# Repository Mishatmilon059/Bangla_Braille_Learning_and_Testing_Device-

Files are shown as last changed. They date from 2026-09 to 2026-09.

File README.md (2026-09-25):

# AI Driven Bangla Braille Learning Device

**Department of Electrical and Electronic Engineering (EEE)**  
**Bangladesh University of Engineering and Technology (BUET)**  
**Course:** EEE 416 — Microprocessor and Embedded Systems Sessional  
**Project Group:** Group 08 (Section A2)  

---

## Project Team Members

| Student Name | Student ID | Academic Affiliation |
|---|:---:|---|
| **Santu Nag** | `2106055` | Department of EEE, Bangladesh University of Engineering and Technology (BUET) |
| **Md. Adib Hasan Audhi** | `2106056` | Department of EEE, Bangladesh University of Engineering and Technology (BUET) |
| **Mishat Hasan Milon** | `2106059` | Department of EEE, Bangladesh University of Engineering and Technology (BUET) |
| **Khalid Mehebub** | `2106065` | Department of EEE, Bangladesh University of Engineering and Technology (BUET) |

---

## Table of Contents

1. [Abstract](#abstract)
2. [System Architecture](#system-architecture)
3. [Hardware Specifications](#hardware-specifications)
4. [Bangla Braille Encoding Standard (50 Characters)](#bangla-braille-encoding-standard-50-characters)
5. [TinyML Pedagogical Model & Empirical Validation](#tinyml-pedagogical-model--empirical-validation)
6. [Repository File & Directory Structure](#repository-file--directory-structure)
7. [Cloning the Repository](#cloning-the-repository)

---

## Abstract

The **Bangla Braille Learning and Testing Device** is an accessible assistive pedagogical system designed for visually impaired learners. Developed as the final capstone design project for **EEE 416 (Microprocessor and Embedded Systems Sessional) at BUET**, the device combines a **6-dot tactile haptic matrix** (coin vibration motors) with **synchronized auditory speech feedback** and an **on-device dual-head neural network** that runs fully offline on an ESP32 microcontroller with zero machine learning runtime overhead. It supports both standalone offline practice and real-time remote classroom assessment via a web-connected teacher portal.

---

## System Architecture

The following diagram illustrates the end-to-end dataflow between specification, training pipelines, the web instrumentation platform, and the physical ESP32 embedded tutor:

```
┌────────────────────────────────────────────────────────────────────────┐
│                        CENTRAL SPECIFICATION                          │
│  spec/engine_spec.json (Features, Thresholds, Normalization Bounds)    │
│  data/braille_map.json (50 Letters, 6-Dot Patterns, Audio Tracks)      │
└───────────────────────────────────┬────────────────────────────────────┘
                                    │
           ┌────────────────────────┼────────────────────────┐
           ▼                        ▼                        ▼
  [tools/gen_engine.py]   [tools/gen_braille_header.py] [tools/gen_audio.py]
           │                        │                        │
  ┌────────┼────────┐               ▼                        ▼
  ▼        ▼        ▼      firmware/braille_map.h       web/audio/ &
web JS   Py Gen   C Header  assets/braille/*.svg         sd_card/mp3/
  │        │        │
  ▼        ▼        │
┌──────┐ ┌──────┐   │
│ Web  │ │ Synth│   │
│ MVP  │ │ Sim  │   │
└──┬───┘ └──┬───┘   │
   │        │       │
   ▼        ▼       │
┌──────────────┐    │
│ 2,242 Rows   │    │
│ (1000 Real + │    │
│  1242 Synth) │    │
└──────┬───────┘    │
       ▼            │
[tools/train.py]    │
       │            │
       ▼            ▼
 ┌──────────────────────────────────────┐
 │       firmware/braille_tutor/        │
 │  model_weights.h (1,734 Floats, 7KB) │
 │  inference.h (0.1ms Forward Pass)    │
 │  rule_engine.h (Fixed Normalization) │
 └──────────────────┬───────────────────┘
                    ▼
 ┌──────────────────────────────────────┐
 │     PHYSICAL EMBEDDED HARDWARE       │
 │ ESP32 · 6 Buttons · 6 Coin Motors    │
 │ ULN2803A · DFPlayer · MicroSD · RTC   │
 └──────────────────────────────────────┘
```

Detailed architectural vector diagrams (SVG and PNG) are located in [`docs/diagrams/`](docs/diagrams/).

---

## Hardware Specifications

### Component List

| Component | Specification | Quantity | Function |
|---|---|:---:|---|
| **Microcontroller** | ESP32-WROOM-32 (38-pin, 240 MHz Dual Core) | 1 | Core compute, TinyML inference, GPIO debounce |
| **Haptic Actuators** | 1027 Coin Vibration Motors (10mm, 3V, 80mA) | 6 | Tactile 6-dot Braille matrix |
| **Motor Driver** | ULN2803A Darlington Transistor Array (DIP-18) | 1 | Inductive load sink & integrated flyback clamping |
| **Input Buttons** | 12×12×7.3mm Tactile Push Buttons | 7 | 6 dot input buttons + 1 submit button |
| **Audio Module** | DFPlayer Mini (FN-M16P MP3 Player) | 1 | Hardware MP3 decoding via UART |
| **Loudspeaker** | 3W 8Ω Enclosed Speaker (40mm) | 1 | Spoken letter pronunciation & audio cues |
| **External Storage** | MicroSD Card SPI Adapter + 16GB MicroSD Card | 1 | Offline storage for 60 spoken audio prompt files |
| **Real-Time Clock** | DS3231 I2C RTC Module | 1 | Session epoch tracking across power cycles |
| **Power Supply** | 5V 2A DC Adapter + 1000 µF 16V Electrolytic Cap | 1 | High-current power rail with inrush decoupling |
| **Resistors & Misc** | 6× 1 kΩ (LED/Pull), 3× 10 kΩ (Strapping pulldowns) | - | Pin protection & pull resistors |
| **Enclosure** | 3D Printed PLA Case & Acrylic Cutout Panel | 1 | Ergonomic desk console housing |

### Canonical Pinout Configuration

The canonical pin assignments (configured in [`firmware/braille_tutor/pins.h`](firmware/braille_tutor/pins.h)) are engineered to avoid ESP32 boot strapping conflicts:

| Peripherals | GPIO Pin | Hardware Configuration & Notes |
|---|:---:|---|
| **Dot Buttons (1–6)** | `GPIO 32, 33, 25, 26, 27, 14` | Internal pull-up enabled (`INPUT_PULLUP`). Active LOW when pressed to GND. |
| **Submit Button** | `GPIO 12` | Boot strapping pin. Pulled to GND during boot; pressed to GND via active switch. |
| **Coin Motors (1–6)** | `GPIO 21, 13, 22, 2, 15, 4` | Connected to ULN2803A Inputs 1–6. Active HIGH drive. ULN2803A COM pin tied to +5V. |
| **DFPlayer Audio** | `GPIO 16 (RX), GPIO 17 (TX)` | ESP32 HardwareSerial (UART2). 1 kΩ series resistor on TX line to suppress noise. |
| **MicroSD Module** | `GPIO 18 (SCK), 19 (MISO), 23 (MOSI), 5 (CS)` | Hardware VSPI interface operating at 20 MHz. |
| **I2C RTC (DS3231)** | `GPIO 21 (SDA), GPIO 22 (SCL)` | Standard I2C bus (optional, activated via `USE_RTC 1` in `pins.h`). |

> [!CAUTION]
> **Electrical Safety & Circuit Protection**:
> **Never drive vibration motors directly from ESP32 GPIOs**: All six coin motors firing simultaneously draw ~480 mA. A ULN2803A Darlington array must be used, with its COM pin tied to +5V for inductive flyback protection.

---

## Bangla Braille Encoding Standard (50 Characters)

The repository implements the official **Bangladesh National Braille Code**, verified against Wikipedia's Bengali Braille standard: [বাংলা ব্রেইল - উইকিপিডিয়া](https://bn.wikipedia.org/wiki/%E0%A6%AC%E0%A6%BE%E0%A6%82%E0%A6%B2%E0%A6%BE_%E0%A6%AC%E0%A7%8D%E0%A6%B0%E0%A7%87%E0%A6%87%E0%A6%B2) and cross-referenced with *World Braille Usage (3rd Edition, Perkins/ICEB)*.

- **11 Vowels**: অ (`1`), আ (`345`), ই (`24`), ঈ (`35`), উ (`136`), ঊ (`1256`), ঋ (`5 + 1235`), এ (`15`), ঐ (`34`), ও (`135`), ঔ (`246`).
- **39 Consonants**: ক (`13`), খ (`1346`), গ (`1245`), ঘ (`126`), ঙ (`346`), চ (`14`), ছ (`16`), জ (`245`), ঝ (`1356`), ঞ (`25`), ট (`23456`), ঠ (`2456`), ড (`1246`), ঢ (`123456`), ণ (`3456`), ত (`2345`), থ (`1456`), দ (`145`), ধ (`2346`), ন (`1345`), প (`1234`), ফ (`124`), ব (`12`), ভ (`1236`), ম (`134`), য (`13456`), র (`1235`), ল (`123`), শ (`146`), ষ (`12346`), স (`234`), হ (`125`), ড় (`12456`), ঢ় (`12356`), য় (`26`), ৎ (`5 + 2345`), ং (`56`), ঃ (`6`), ঁ (`3`).

### Two-Cell Compound Characters (ঋ and ৎ)
In Bengali orthography, ঋ (*ri*) and র (*ra*) share the primary dot matrix `[1, 2, 3, 5]`, while ত (*ta*) and ৎ (*khanda ta*) share `[2, 3, 4, 5]`. To resolve this collision haptically without tactile ambiguity:
- **Two-Cell Representation**: ঋ and ৎ are encoded as two sequential Braille cells.
- **Haptic Timing**: In Learn and Tutor modes, an initial 150 ms pulse on **Dot 5** serves as the indicator prefix, followed by a 200 ms pause, followed by the vibration of the primary letter cell.

---

## TinyML Pedagogical Model & Empirical Validation

### Network Architecture

The on-device pedagogical agent uses a dual-head feedforward neural network:

$$\mathbf{x} \in \mathbb{R}^8 \longrightarrow \text{Dense}(32, \text{ReLU}) \longrightarrow \text{Dense}(16, \text{ReLU}) \longrightarrow \begin{cases} \text{Head}_{\text{TA}} \in \mathbb{R}^3 & (\text{Teaching Action}) \\ \text{Head}_{\text{CS}} \in \mathbb{R}^3 & (\text{Confidence State}) \end{cases}$$

1. **Total Parameters**: 1,734 trainable floating-point weights (6,936 bytes).
2. **Execution Latency**: **~0.1 milliseconds** on an ESP32 at 240 MHz.
3. **Memory Footprint**: 6,936 bytes in Flash (`PROGMEM`) + 192 bytes temporary stack RAM during forward pass. Total memory required: **~7.1 KB of 520 KB SRAM** (< 1.4% capacity).

### Feature Formulation (8 Model Inputs of 14 Logged)

| Feature Name | Type | Range | Description |
|---|:---:|:---:|---|
| `response_time` | float | 0–30,000 ms | Elapsed time from prompt completion to debounced submit press |
| `press_duration` | float | 0–5,000 ms | Average hold duration across raised dot keys |
| `retry_count` | int | 0–10 | Number of re-attempts within the current character trial |
| `prev_accuracy` | float | 0.0–1.0 | Exponential moving average of learner accuracy across past attempts |
| `prev_mastery` | float | 0.0–1.0 | Historical mastery score for the specific character prompt |
| `hint_count` | int | 0–10 | Frequency of tactile/audio hints requested during the trial |
| `current_streak` | int | 0–50 | Number of consecutive correct submissions |
| `wrong_streak` | int | 0–20 | Number of consecutive incorrect submissions |

### Experimental Results (Evaluated on 2,242 Total Trials)

| Task Head | Class Label | Test Support ($N$) | Precision | Recall | F1-Score | Combined Accuracy | Real-Only Accuracy | Majority Baseline |
|---|---|:---:|:---:|:---:|:---:|:---:|:---:|:---:|
| **Teaching Action** | `REPEAT` | 90 | 1.000 | 0.989 | **0.994** | **99.41%** | **98.56%** | 46.59% |
| | `HINT` | 90 | 0.978 | 1.000 | **0.989** | | | |
| | `NORMAL_PRACTICE` | 157 | 1.000 | 0.994 | **0.997** | | | |
| **Confidence State** | `CONFIDENT` | 94 | 0.910 | 0.968 | **0.938** | **94.07%** | **91.37%** | 42.43% |
| | `HESITANT` | 143 | 0.956 | 0.902 | **0.928** | | | |
| | `GUESSING` | 100 | 0.951 | 0.970 | **0.960** | | | |

---

## Repository File & Directory Structure

```
.
├── assets/
│   └── braille/                     # Generated vector SVGs and PNG contact sheets for all 50 characters
├── Bangla_Braille_39_Consonants_PNG/# 39 Consonant reference cards citing World Braille Usage (3rd Ed.)
├── braille_img/                     # Ground-truth reference images for Bengali vowels
├── data/
│   ├── braille_map.json             # Primary ground truth: 50 letters, dot arrays, audio mappings
│   ├── braille_verified/            # Cropped verification cell images
│   └── braille_verified.zip         # Packaged visual verification archives
├── dataset/
│   ├── real.csv                     # Raw human participant trial logs (P01-P04)
│   ├── real_v2.csv, real_v3.csv     # Preprocessed and validated human attempt datasets (1,000 trials)
│   ├── synthetic.csv                # Calibrated synthetic learner simulations
│   ├── synthetic_2k.csv             # 1,242 synthetic rows matched to empirical distributions
│   └── synthetic_targeted.csv       # Targeted rare-class training samples
├── docs/
│   ├── diagrams/                    # System diagrams (PNG & SVG)
│   ├── presentation/                # Academic presentation slide decks and progress reports
│   │   ├── BraillePresentation.pptx # Technical presentation slides
│   │   ├── EEE416_G8_FinalDemo.pptx # Final demonstration deck
│   │   └── G8 Project Progress.pdf  # Project milestone documentation
│   ├── FINAL_DEMO_CHECKLIST.md      # Hardware demonstration and QA checklist
│   └── PROJECT_REPORT.md            # Comprehensive scientific technical report
├── enclosure/
│   ├── 3d_preview.html              # Interactive Three.js 3D web preview of the enclosure
│   ├── braille_tutor_case.scad      # OpenSCAD 3D parametric desk console case
│   ├── top_panel.stl                # Ready-to-print 3D mesh for top button/motor panel
│   ├── top_panel_cutout.svg         # 1:1 scale 2D vector file for laser-cut acrylic top plates
│   └── top_panel_layout.scad        # Parametric layout generator for component cutouts
├── firmware/
│   ├── braille_tutor/               # Main autonomous offline embedded firmware
│   │   ├── braille_map.h            # [Generated] 50-letter dot lookup tables & prefix flags
│   │   ├── braille_tutor.ino        # Core microcontroller application loop
│   │   ├── hardware.h               # Peripheral abstractions (audio, motors, debounce)
│   │   ├── inference.h              # Pure C forward pass for 1,734-param neural network
│   │   ├── learner_state.h          # On-device feature tracker and moving average calculator
│   │   ├── model_weights.h          # [Generated] Static C float arrays of trained MLP weights
│   │   ├── pins.h                   # Canonical GPIO pin mappings and hardware macros
│   │   ├── platformio.ini           # PlatformIO project configuration
│   │   └── rule_engine.h            # [Generated] Feature normalizer & rule fallback logic
│   ├── t11_ml_test/                 # Side-by-side firmware comparing TinyML decisions vs rule engine
│   ├── t12_ml_complete/             # t11_ml_test + per-student personalization (real student_id, saved mastery per student)
│   └── tests/                       # Staged bring-up sketches (t1_blink to t11_testing)
├── models/
│   ├── golden_vectors.json          # 20 boot self-test vectors with expected model outputs
│   ├── metrics_final.json           # Comprehensive evaluation metrics, confusion matrices & F1 scores
│   └── model.tflite                 # 8-bit quantized reference model
├── sd_card/
│   └── mp3/                         # 60 zero-padded MP3 audio files (0001.mp3 to 0060.mp3) for DFPlayer
├── spec/
│   └── engine_spec.json             # Central specification for features, thresholds, and outputs
├── supabase/
│   ├── full_setup.sql               # Complete idempotent database schema (commands, attempts, telemetry)
│   └── schema.sql                   # Base attempts table schema
├── tools/                           # Python pipelines for code generation, training & validation
│   ├── gen_audio.py                 # Generates spoken audio prompts via TTS
│   ├── gen_braille_header.py        # Generates firmware/braille_tutor/braille_map.h
│   ├── gen_braille_images.py        # Generates vector and PNG character visual representations
│   ├── gen_engine.py                # Transpiles engine_spec.json into JS, C, and Python rule engines
│   ├── run_all_tests.py             # Master automated validation suite
│   ├── test_parity.py               # Cross-runtime parity verification (JS == C == Python)
│   ├── train_and_export.py          # Trains dual-head MLP and exports model_weights.h
│   └── validate_braille_map.py      # Verifies 50 characters against national standard
├── web/                             # Browser data-collection application & teacher telemetry portal
│   ├── audio/                       # Web-optimized audio assets
│   ├── data/braille_map.json        # Frontend character configuration
│   ├── app.js                       # Core interactive student tutor web client
│   ├── config.js                    # Supabase public client connection configuration
│   ├── index.html                   # Student practice & data collection interface
│   ├── teacher.html, teacher.js     # Real-time remote teacher control & assessment dashboard
│   ├── remote_control.html          # Lightweight single-character trigger panel
│   └── rule_engine.js               # [Generated] In-browser pedagogical classification engine
├── package.json                     # Project manifest and dev server scripts
├── requirements.txt                 # Python dependencies
└── USER_MANUAL.md                   # Bengali user guide for participant testing
```

---

## Cloning the Repository

To clone this repository and inspect the project files:

```bash
git clone https://github.com/Mishatmilon059/Bangla_Braille_Learning_and_Testing_Device-.git
cd Bangla_Braille_Learning_and_Testing_Device-
```

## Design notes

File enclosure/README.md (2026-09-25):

# Bangla Braille Tutor — enclosure & fabrication

Mechanical files for the ESP32 Bangla Braille Tutor console. The top face is
the part that matters: it carries every component the learner touches.

## Three parts, one enclosure

The enclosure is three separate printed parts, stacked and screwed together:

1. **`top_panel.stl`** — the flat top panel. Already printed.
2. **`case_walls.stl`** — an open-top, open-bottom frame the panel rests
   on. **Print this next.**
3. **`case_base.stl`** — a flat cover that closes the bottom. **Print this
   too.**

`case_walls.stl` and `case_base.stl` are generated straight from
`tools/gen_case_parts_3d.py`, the same no-OpenSCAD-needed approach as
`top_panel.stl` -- `case_walls.scad` / `case_base.scad` are the OpenSCAD
source of truth for the same two parts, for anyone who does have OpenSCAD.

Stack order, bottom to top: the base cover, then the wall frame, then the
top panel on top. Four M3 screws drop down
through the panel's four corner holes, through the frame's open interior,
into the screw bosses moulded into the base cover.

Heights: 2.8 mm (panel) + 45.2 mm (walls) + 2.8 mm (base) = 50.8 mm (2 in)
total, ground to top panel. All three share the same 210 × 140 mm footprint
and 8 mm corner radius (from `top_panel_layout.scad`), so nothing needs
separate measuring — they line up by construction.

## Files

### The top panel, which is the part that gets made

| File | Purpose | Opens in |
|---|---|---|
| `top_panel.stl` | **The 3D top panel.** Watertight solid, mm, print or view it. **Generated.** | Cura, PrusaSlicer, Bambu Studio, any mesh viewer |
| `top_panel_3d.html` | **3D viewer for the top panel.** Orbit, preset views. **Generated.** | any browser (needs internet for the CDN) |
| `top_panel_cutout.svg` | 1:1 cut file for the same panel. **Generated.** | Laser cutter, Illustrator, CorelDRAW, Inkscape |
| `top_panel_layout.scad` | The same coordinates as OpenSCAD constants. **Generated.** | included by the case file |

### The rest

| File | Purpose |
|---|---|
| `case_walls.stl` | **The middle part.** Watertight solid, mm, ready for a slicer. An open-top/open-bottom frame, 45.2 mm tall, same footprint and corner radius as the top panel. No panel cutouts (motor/button/speaker) — those are already on the printed panel. Carries the wire pass-through hole, offset to one side of the back wall. **Generated.** |
| `case_base.stl` | **The base half.** Watertight solid, mm, ready for a slicer. Closes underneath: a 2.8 mm flat cover, same footprint and corner radius as the top panel, with M3 screw bosses under the panel's clearance holes. **Generated.** |
| `case_walls.scad` | OpenSCAD source of truth for `case_walls.stl`, for anyone who has OpenSCAD instead of Python |
| `case_base.scad` | OpenSCAD source of truth for `case_base.stl` |
| `braille_tutor_case.scad` | Superseded. An all-in-one alternative that merges the top panel and the walls into a single printed part — duplicates `top_panel.stl` rather than pairing with it. Use `case_walls.stl`/`.scad` instead unless you want a single-part top half printed from scratch |
| `3d_preview.html` | Superseded. An older mockup of the whole console with a layout that no longer matches anything. Nothing is made from it. |
| `case_full_3d.html` | 3D viewer: base cover only, side walls only, or the complete assembly (with the already-printed top panel shown for reference). **Generated by hand, not a script** -- built to the same numbers as the two `.scad` files |

Every generated file traces to one place. Re-run these after any change; never
hand-edit the outputs.

```
python tools/gen_top_panel.py       # SVG + SCAD layout, validates clearances
python tools/gen_top_panel_3d.py    # top_panel.stl + its HTML viewer
python tools/gen_case_parts_3d.py   # case_walls.stl + case_base.stl
```

[`tools/gen_top_panel.py`](../tools/gen_top_panel.py) holds the numbers.
[`tools/gen_top_panel_3d.py`](../tools/gen_top_panel_3d.py) and
[`tools/gen_case_parts_3d.py`](../tools/gen_case_parts_3d.py) import them, so
none of the three printed parts can drift out of alignment with each other.

### The STL

A flat plate, 210 x 140 x 2.8 mm, with all 54 holes. No walls, no skirt, no
base. It is built without a mesh library, so it is verified rather than
trusted:

| Check | Result |
|---|---|
| Triangles | 12,184 |
| Non-manifold edges | 0, watertight |
| Volume vs analytic | agrees to 1.7e-15 relative |
| Bounding box | 210.000 x 140.000 x 2.800 mm |
| Degenerate triangles | 0 |

Printed in PLA at 100% that is about 96 g of material. Print it flat on the
bed, holes vertical, no supports needed.

### The viewer renders the same mesh

`top_panel_3d.html` embeds the verified triangulation rather than rebuilding
the shape in the browser. `THREE.ExtrudeGeometry` is deliberately not used:
its hole bridging emits degenerate slivers, and `EdgesGeometry` then infers
edges along them, which drew a phantom line joining two neighbouring button
holes. The panel itself was solid there the whole time. Outlines are now drawn
straight from the ring loops, so nothing is inferred and the viewer cannot
disagree with the STL.

### Spacing between holes

Both grids share a 30 mm pitch, horizontally and vertically.

| Between | Pitch | Hole | Gap of material |
|---|---|---|---|
| Button to button, left-right | 30 mm | 12.4 mm | 17.6 mm |
| Button to button, top-down | 30 mm | 12.4 mm | 17.6 mm |
| Motor to motor, left-right | 30 mm | 10.4 mm | 19.6 mm |
| Motor to motor, top-down | 30 mm | 10.4 mm | 19.6 mm |

The submit button keeps the same 30 mm pitch below the last button row, so it
also has 17.6 mm of material above it.

The generator refuses to pass if any two cuts come within 2 mm of each other
or of the panel rim. Current worst cases: 6.40 mm of material from a corner
screw to the rim, and a 2.50 mm web between two adjacent grill holes.

## Parts the top face is cut for

| Component | Qty | Part size | Cutout |
|---|---|---|---|
| Tactile push button, 4-pin | 7 | 12.0 × 12.0 mm body, 6.0 mm tall | 12.4 mm square, 0.5 mm corner relief |
| Coin vibration motor | 6 | Ø 10.0 mm, 3.0 mm thick | Ø 10.4 mm |
| Speaker | 1 | Ø 40.0 mm | 37 × Ø 2.5 mm over a Ø 34.5 mm area |
| M3 machine screw | 4 | M3 | Ø 3.2 mm |

Button caps are white for dots 1–3, red for dots 4–6, and yellow for submit.

**Fit.** Every cutout is 0.4 mm larger than its part, 0.2 mm per side. Cut on
the path centreline and let the kerf give the running clearance; on a laser
that typically lands within a tenth of a millimetre.

Button bodies press **up** through their square holes, so the 2.8 mm panel
captures each switch just under its cap and 3.2 mm of body stands proud.
Motors bond into their round holes with the face **flush** to the panel top,
so the fingertip rests on the motor itself rather than on plastic over it.
Motor leads pass back down through the same hole.

## Layout

210 × 140 mm, 8 mm corner radius, 2.8 mm sheet.

Two 3 × 2 blocks share one 30 mm grid, with rows at y = 26, 56 and 86 mm.
Dots 1-2-3 run down the left column of each block and 4-5-6 down the right,
so dot N sits on the same line whether the learner is feeling it or pressing
it. The motor block centres on x = 52, the button block on x = 158, and the
submit button sits between the two button columns at x = 158, y = 116,
carrying the same 30 mm pitch down from the last row.

The speaker grill centres on x = 105, the exact panel centre line, at
y = 112. Its perforated area stops at Ø 34.5 mm so the Ø 40 mm speaker frame
seats against solid material.

Corner screws sit 8 mm in from both edges, on the corner-radius centres.

## The side walls

`case_walls.scad` is an open-top, open-bottom rounded-rectangle tube that the
already-printed top panel rests on. It shares `PANEL_W`, `PANEL_H` and
`CORNER_R` from `top_panel_layout.scad`, so its footprint and corner radius
match the panel exactly -- the panel sits flush on its top rim, no fitting.

Height: the brief is a total assembled height of 2 in (50.8 mm), ground to
top panel. The panel itself is 2.8 mm and the base cover (below) is another
2.8 mm, so the walls carry the rest: 50.8 - 2.8 - 2.8 = 45.2 mm.

It has none of the panel's own cutouts (motor, button, speaker) -- those are
already on the printed panel. The four M3 screws that pass down through the
panel's corner holes land inboard of the wall thickness, in the frame's open
interior, so the walls don't need their own screw holes either.

| Property | Value |
|---|---|
| Footprint | 210 × 140 mm, 8 mm corner radius (same as the top panel) |
| Height | 45.2 mm |
| Wall thickness | 2.8 mm, matching the top panel |
| Wire pass-through | Ø 8 mm round hole through the back wall, offset to one side (x = 40, not the wall's centre at x = 105) at z = 20 mm, for the power/USB cable |

- **Material:** PLA, PETG or ABS
- **Layer height:** 0.20 mm, or 0.16 mm for a smoother finish
- **Infill:** 20–30% gyroid or grid
- **Supports:** none needed; open top and bottom, no overhangs

`case_walls.stl` is built as 8 independent solids (4 corners, 4 straight
strips, one of them with the wire hole actually cut through it) concatenated
into one file -- they only ever touch a neighbour at a shared, zero-area
face, never overlap, so each is checked on its own:

| Check (each of the 8 pieces) | Result |
|---|---|
| Non-manifold edges | 0, watertight |
| Volume vs analytic | within 0.1%, the polygon-vs-circle/arc discretisation |
| Degenerate triangles | 0 |
| Total | 996 triangles, 85,596.6 mm3 |

## The base cover

`case_base.scad` closes underneath the walls. Same footprint and corner
radius as the top panel and the walls, so all three line up without fitting.

| Property | Value |
|---|---|
| Footprint | 210 × 140 mm, 8 mm corner radius (same as the top panel) |
| Thickness | 2.8 mm (flat cover) |
| Assembled height | 2.8 mm panel + 45.2 mm walls + 2.8 mm cover = 50.8 mm (2 in) total |
| Screw bosses | 4, Ø 7 mm OD × 10 mm tall, Ø 2.6 mm self-tapping pilot for M3, centred on the same `SCREW_POS` as the top panel's clearance holes; they rise into the walls' clear interior |

Flat and thin, it prints supportless, flat side down, same as the top panel.

- **Material / layer height / infill:** same as the walls, above.
- **Fasteners:** the same 4 × M3 screws that pass through the top panel and
  down through the walls thread into these bosses from underneath.

`case_base.stl` is the plate plus the 4 bosses, 5 independent solids
(touching, not overlapping) concatenated the same way as the walls:

| Check (each of the 5 pieces) | Result |
|---|---|
| Non-manifold edges | 0, watertight |
| Volume vs analytic | within 0.3% (the bosses' small radius makes their circle-discretisation error the largest of any part here) |
| Degenerate triangles | 0 |
| Total | 1,932 triangles, 83,489.0 mm3 |

## Known gap

`3d_preview.html` hardcodes its own copy of the geometry and still shows the
older layout: round button holes, a different grid, and a smaller grill. It is
a presentation mockup, not a fabrication source, so nothing is cut or printed
from it. Regenerate or retire it before using it to check dimensions.

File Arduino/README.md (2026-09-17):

# Arduino sketchbook — bench prototypes

This folder is the Arduino IDE sketchbook used while the hardware was being
built on a breadboard. Point the IDE at this directory (File > Preferences >
Sketchbook location) and the bundled `libraries/DFRobotDFPlayerMini` is picked
up automatically, so nothing needs installing.

These are **not** the shipping firmware. The deliverable is
[`firmware/braille_tutor/`](../firmware/braille_tutor/), with its staged
bring-up sketches in [`firmware/tests/`](../firmware/tests/). What lives here is
the earlier, single-file lineage that proved each peripheral by hand.

## Read this before flashing anything

The pin assignments here are the ones that were physically wired on the
breadboard. They are **different from** the canonical map in
[`firmware/braille_tutor/pins.h`](../firmware/braille_tutor/pins.h), which moved
the buttons and motors onto pins chosen for their pull-ups and strapping
behaviour. Do not mix a sketch from this folder with wiring built to `pins.h`.

| | this sketchbook | `pins.h` |
|---|---|---|
| dot buttons | 4, 5, 15, 19, 21, 22 | 32, 33, 25, 26, 27, 14 |
| motors | 13, 14, 26, 27, 32, 33 | 13, 4, 21, 22, 2, 15 |
| DFPlayer RX / TX | 25 / 23 | 16 / 17 |
| submit / enter | 18 / 23, 34 or 16 | 34 (submit) |

## The sketches, in the order they were built

| # | Sketch | Adds | Input |
|---|---|---|---|
| 1 | `p1_pin_tester` | nothing — raw pin diagnostic, no debounce | buttons |
| 2 | `p2_motor_letters` | six vibration motors | serial, 1-37 |
| 3 | `p3_audio_and_vibrate` | DFPlayer audio on top of the motors | serial, 1-50 |
| 4 | `p4_chord_typing` | 6-dot chord input, submit, enter | buttons |
| 5 | `p5_chord_audio_vibrate` | buttons + audio + vibration together | buttons |
| 6 | `p6_dual_mode` | typing mode (audio only) and tutor mode (audio + vibration) | buttons and serial |

## The one that works: `milse1`

`milse1` is the build confirmed working on the bench: speaker, all seven
buttons and all six motors. Flash this one to demo the breadboard. The `p*`
sketches above are the history that led to it.

It is `p6_dual_mode` with five differences:

| | `p6_dual_mode` | `milse1` |
|---|---|---|
| Enter button | GPIO 16, `INPUT_PULLUP` | GPIO 34, plain `INPUT` |
| DFPlayer pin macros | `PIN_DF_RX` / `PIN_DF_TX` | `PIN_DF_ESP_RX` / `PIN_DF_ESP_TX` |
| Track addressing | `playMp3Folder()` | `play()` |
| Volume | 22 | 25 |
| Settle before `begin()` | 500 ms | 1000 ms |

Three notes on it, none a reason to change working hardware:

- **`play()` rather than `playMp3Folder()`.** `play(n)` takes the nth file in
  the card's index order rather than resolving `/mp3/000n.mp3` by name. It is
  correct here because the card was written once, in order, with nothing else
  on it. Rewrite or reorder the card and the mapping can shift.
- **Enter on GPIO 34 with plain `INPUT`.** More honest than the
  `INPUT_PULLUP` it replaced, since GPIO 34 has no internal pull-up to
  enable. The pin still floats without an external 10k to 3V3, so Enter can
  self-trigger. Add the resistor if you see phantom message prints.
- **The `begin()` failure branch is unreachable.** With `isACK` false the
  library returns `... || !isACK`, so those four "Check:" hints never print.
  Harmless while the audio works; misleading the next time it does not.

## `final_working_20260907_1017`

Saved 7 September 2026, 10:17. Same hardware and pins as `milse1`, but a
different program and a different Braille table.

The program is a three-mode menu driven over serial: `L` enters Learn, which
speaks a letter and vibrates its dots; `T` enters Test, which speaks a letter
and scores the dots you press; `M` or the Enter button returns to the menu and
prints the running score. It has no typing-to-text mode, so nothing does a
reverse pattern lookup.

**Its `BRAILLE_PATTERN` table is not usable as ground truth.** Every hex value
does agree with its own dot-list comment, so there are no transcription typos,
but the table itself is not one-to-one:

- **34 distinct patterns for 50 letters.** Twelve patterns are shared by 28
  letters. Dots 1-4-5 is listed as the answer for ঈ, ঙ and দ at once; dots
  1-2-4-5 for ঋ, গ and ং; dots 1-2-4-5-6 for ও, ঢ and ড়. Six dots give 63
  distinct non-empty patterns, so 50 letters fit with room to spare. Collisions
  mean the chart was misread, not that the encoding ran out of room.
- **It contradicts `firmware/braille_tutor/braille_map.h` on 33 of 50
  letters**, including 10 of the 11 that map marks as verified against a
  supplied chart image. For আ the verified pattern is dots 3-4-5 and this table
  says dots 1-2.

Test mode still scores each question, because it compares against the pattern
at a known index rather than searching. But a collided letter teaches the
learner two contradictory answers, and rows logged from it would corrupt the
training set. `tools/validate_braille_map.py` exists for exactly this check and
says so in its own docstring. Reconcile the chart against the images in
`braille_img/` before treating this table as correct.

## Known problems, kept unfixed on purpose

Each sketch reproduces what was actually on the bench, so the flaws are
documented rather than patched. The fixes all live in the `firmware/` tree.

- **GPIO 34 has no internal pull-up.** `p5` calls
  `pinMode(enterButtonPin, INPUT_PULLUP)` on GPIO 34, which is input-only. The
  call is a no-op and the button floats. It needs an external 10k to 3V3.
  `p6` has since moved Enter to GPIO 16, which does have one. Note that
  GPIO 16/17 are wired to PSRAM on ESP32-WROVER modules and unusable there;
  `p6` assumes a WROOM.
- **GPIO 23 is triple-booked.** It is "Submit" in `p1`, "Enter" in `p4`, and the
  DFPlayer TX line in `p5`/`p6`.
- **`p2` carries a stale dictionary.** Its 37-letter table disagrees with the
  canonical 50-letter table on three characters: খ (`0x2D` vs `0x28`), ঝ (`0x35`
  vs `0x34`) and ভ (`0x27` vs `0x18`). The 50-letter table in `p3`/`p5`/`p6`
  matches `firmware/braille_tutor/braille_map.h` and is the one to trust.
- **`p3` sets an out-of-range volume.** `dfPlayer.volume(50)`; the part accepts
  0-30. `p5` uses 30 and `p6` uses 22.
- **`p3` and `p5` address audio with `play()`, `p6` with `playMp3Folder()`.**
  `play(n)` takes the nth file in the card's index order, which depends on the
  order the files were written. `playMp3Folder(n)` resolves `/mp3/000n.mp3` by
  name and is the reliable one, but it needs `mp3/` at the card root. Copy the
  contents of `sd_card/`, not the `sd_card` folder itself.
- **Keep `begin()`'s isACK argument true.** The library returns
  `... || !isACK`, so passing false makes `begin()` report success with no
  module attached, and disables the acknowledgement that would surface any
  later command failure. A dead DFPlayer then looks exactly like a working
  one.
- **ঋ and র share pattern `0x17`.** The decoders skip index 6 during the
  one-cell search, so a bare `0x17` chord resolves to র and ঋ is reachable only
  through the dot-5 two-cell prefix.

## `_archive/`

`chord_typing_dot6_prefix` is an earlier `p4` that used a **dot-6** prefix for ৎ
and a dot-5 prefix for ঋ. That was dropped in favour of a single dot-5 prefix
for both, which is what `p4`, `p5` and `p6` implement. Kept only for the
history; the IDE will still open it.

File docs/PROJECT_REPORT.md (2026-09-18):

# AI-Assisted Bangla Braille Tutor — End-to-End Project Report

**Repository:** `Mishatmilon059/Bangla_Braille_Learning_and_Testing_Device-`
**Branch:** `main`
**Report date:** 30 July 2026
**Status:** software complete and tested · data collection not started · hardware not built

---

## 1. What this project is

A system that teaches Bangla Braille, records how learners perform, trains a
small neural network on those recordings, and runs that network **entirely
offline on an ESP32 microcontroller** driving six vibration motors, six push
buttons, and spoken audio.

It has three parts:

| Part | Purpose | Status |
|---|---|---|
| **Web MVP** | Data-collection instrument. Teaches, and records every attempt. | ✅ Built and tested |
| **Training pipeline** | CSV → multi-task network → 8-bit model → C header | ✅ Built and tested |
| **ESP32 firmware** | Runs the model on hardware, no internet | ✅ Written, ⚠ not run on real hardware |

---

## 2. Honest summary — read this first

Three statements that must appear in any write-up of this project:

**2.1 The model imitates a rule engine; it does not discover teaching policy.**
The training labels are produced by a hand-written rule engine. A network
trained on them learns to reproduce that rule engine — measured at 100%
agreement on this synthetic-only run. This is a legitimate TinyML result
(train → quantize → deploy → real-time offline inference in 5,480 bytes), but
describing it as autonomous adaptive learning would be false. One question —
*"where did the labels come from?"* — exposes the difference.

**2.2 No real learner data exists yet.** Every accuracy figure in this report
comes from a synthetic-data pipeline test. Those numbers are circular: the rows
were simulated and labelled by the same rule engine the network is asked to
reproduce. They prove the *pipeline* works. They say nothing about real people.

**2.3 39 of 50 Braille characters are unverified.** The 11 vowels were read
from supplied reference images. The 39 consonants still carry placeholder
patterns derived from the Bharati Braille standard. Evidence they are not
reliable: of 11 vowel guesses, **1 was wrong**. At that rate roughly 3–4
consonants are also wrong, and there is no way to tell which without images.

---

## 3. Architecture

```
                        ┌──────────────────────────┐
                        │  spec/engine_spec.json   │  ← source of truth
                        │  data/braille_map.json   │
                        └────────────┬─────────────┘
                                     │  code generators
              ┌──────────────────────┼──────────────────────┐
              ▼                      ▼                      ▼
      web/rule_engine.js    tools/rule_engine_gen.py   firmware/rule_engine.h
              │                      │                      │
              ▼                      ▼                      ▼
      ┌───────────────┐      ┌──────────────┐      ┌────────────────┐
      │  Web MVP      │      │  Synthetic   │      │  ESP32         │
      │  (browser)    │      │  generator   │      │  firmware      │
      └───────┬───────┘      └──────┬───────┘      └────────┬───────┘
              │ real rows           │ synthetic rows        │
              └──────────┬──────────┘                       │
                         ▼                                  │
                  ┌─────────────┐                           │
                  │  Supabase   │                           │
                  │  attempts   │                           │
                  └──────┬──────┘                           │
                         ▼                                  │
                  ┌─────────────┐                           │
                  │  train.py   │  790 params               │
                  └──────┬──────┘                           │
                         ▼                                  │
                  model.tflite (5,480 B int8) ──────────────┘
```

### 3.1 The central design decision

Everything downstream is **generated from two data files**. This exists to
eliminate one specific failure: the browser and the ESP32 computing features or
rules slightly differently, so a model trained on browser data misbehaves on
hardware. That class of bug is invisible until integration and expensive to
find then.

The rule engine is written **once** in `spec/engine_spec.json` and generated
into JavaScript, C, and Python. `tools/test_parity.py` pushes **3,000 feature
vectors** — including values sitting exactly on every decision threshold —
through all three and asserts identical output for the teaching action, the
confidence state, and all 14 normalized values. It passes.

Feature normalization uses **fixed ranges from the spec, not statistics derived
from the dataset**. A dataset-derived scale would shift every time the model is
retrained, silently desynchronising the ESP32 from the model it is running.

---

## 4. The learning model

### 4.1 Features — 14 logged, 4 fed to the model

All 14 are sampled at three distinct moments (web and firmware must sample
identically or the model misbehaves on hardware) and kept in the database/CSV
schema for logging and analysis. Only the 4 marked **model input** below are
actually fed to the neural network — the other 10 are read by no rule in
`spec/engine_spec.json`, so the model has nothing to gain from seeing them.
`hint_count` in particular is now an exact function of `retry_count`
(`hint_count = max(0, retry_count-1)` under the current rules), not just
weakly correlated with it.

| # | Feature | Unit | Sampled | Model input? |
|---|---|---|---|---|
| 1 | `char_id` | 0–49 | before attempt | — |
| 2 | `response_time` | ms | during attempt | ✅ |
| 3 | `press_duration` | ms | during attempt | ✅ |
| 4 | `retry_count` | count | during attempt | ✅ |
| 5 | `prev_accuracy` | 0–1 | before attempt | — |
| 6 | `prev_mastery` | 0–1 | before attempt | — |
| 7 | `hint_count` | count | during attempt | — |
| 8 | `session_number` | count | before attempt | — |
| 9 | `difficulty_level` | 1–5 | before attempt | — |
| 10 | `time_since_last_practice` | s | before attempt | — |
| 11 | `prev_confidence` | 0–2 | before attempt | — |
| 12 | `current_streak` | count | **after attempt** | — |
| 13 | `wrong_streak` | count | **after attempt** | ✅ |
| 14 | `prev_mistakes` | count | before attempt | — |

**There is deliberately no `is_correct` feature.** Because the two streaks are
sampled *after* scoring, correctness is derivable: `current_streak > 0` means
the attempt was correct, `wrong_streak > 0` means it was wrong, and exactly one
is non-zero. This matters — the rule engine branches on `wrong_streak`. Had the
streaks been sampled before scoring, the engine would be branching on
information absent from the model's input, and accuracy would cap out for
reasons that look like a training bug but are not. `current_streak` is kept as
a logged column (it still gates nothing once `INCREASE_DIFFICULTY`/
`WORD_PRACTICE` were removed, see §4.2) but is no longer a model input either.

### 4.2 Outputs

- **Teaching action (3):** Repeat · Hint · Normal Practice
  `Increase Difficulty`, `Review Previous`, and `Word Practice` were removed:
  `difficulty_level` was never read back by anything once removed as a rule
  condition, `Word Practice` had no word-level content built, and abandoning
  the current letter after 3 wrong tries taught nothing about the letter the
  learner actually needed — the rules now keep giving `Hint` on the same
  letter for every wrong try after the first, uncapped.
- **Confidence state (3):** Confident · Hesitant · Guessing

### 4.3 Network

```
Input(4) → Dense(32, ReLU) → Dense(16, ReLU) → ┬→ Dense(3, softmax)  confidence
                                                └→ Dense(3, softmax)  teaching
```

**790 trainable parameters.** Trains in seconds on a laptop CPU; no GPU.

| Layer | Params | Calculation |
|---|---|---|
| Dense 32 | 160 | 4×32 + 32 |
| Dense 16 | 528 | 32×16 + 16 |
| Dense 3 (confidence) | 51 | 16×3 + 3 |
| Dense 3 (teaching) | 51 | 16×3 + 3 |
| **Total** | **790** | |

Class balancing is folded into the loss function because Keras 3 rejects both
`class_weight` and `sample_weight` on multi-output models. Without it the rare
teaching actions are ignored in favour of the majority class, which reads as
good accuracy and is useless.

---

## 5. Results (pipeline validation only — no real data)

From `models/metrics.json`, trained on 600 synthetic rows:

| Metric | Value | Interpretation |
|---|---|---|
| Trainable parameters | 790 | |
| Teaching action accuracy | 100% | vs 49.5% majority baseline |
| Confidence state accuracy | 98.9% | vs 47.3% majority baseline |
| Rule-engine agreement | 100% | expected — the labels *are* the rule engine |
| TFLite vs Keras agreement (teaching) | **29.7%** | int8 quantization badly mismatched this run — see warning below |
| Quantized model size | **5,480 bytes** | |
| Real-data accuracy | **N/A** | no real rows collected |

⚠ **The 29.7% TFLite-vs-Keras figure is a real warning, not a typo.** On this
particular 600-row synthetic-only run, int8 quantization shifted the teaching
head's predictions far more than the training script's own 97% threshold
allows (`train.py` prints this warning itself). The deployed `.tflite` is
*not* the model validated above for the teaching head, even though the
confidence head quantized cleanly (100%). This is a known risk with a small,
narrow-range synthetic dataset and representative-sample quantization; it must
be re-checked after retraining on real data, and is exactly the kind of thing
`test_firmware_headers.py`'s golden-vector self-test exists to catch on the
actual board before it does any harm — a mismatch there makes the firmware
fall back to the plain rule engine automatically.

The majority baseline is reported beside every accuracy because "100%
accurate" is unreadable without it — a model barely above baseline has learned
almost nothing.

### 5.1 Memory footprint on ESP32

| Item | Size |
|---|---|
| Model | 5,480 B |
| Tensor arena | 8 KB |
| **Total** | **13.4 KB of 520 KB SRAM (2.6%)** |

**Model size was never a risk on this project.** The constraints are recruiting
participants and building hardware.

---

## 6. Data strategy: 40% real / 60% synthetic

### 6.1 Order is load-bearing

Collect real data **first**, fit distributions to it, *then* generate synthetic
data. Reversed, the synthetic rows are sampled from guessed ranges that
resemble nothing, and the model learns a distribution that does not exist.

### 6.2 Simulation, not sampling

`tools/gen_synthetic.py` **simulates virtual learners** through the same state
machine the web app uses, rather than sampling the 14 features independently.
Independent sampling produces impossible combinations — `current_streak = 7`
beside `prev_mastery = 0.02` — that cannot occur in reality and waste model
capacity on a region that will never be seen.

### 6.3 Rare classes

Some classes occur rarely in natural use. The generator tops these up with
scenarios **capable of producing them**: `CONFIDENT` needs a fast, clean,
first-try answer, which a struggling learner rarely gives no matter how long
the simulation runs, so that class draws a strong learner drilling a small
character pool instead. `REPEAT`, `HINT`, and `NORMAL_PRACTICE` all show up
naturally in the main population once `WORD_PRACTICE`/`INCREASE_DIFFICULTY`/
`REVIEW_PREVIOUS` were removed from `teaching_action` (see §4.2) — there is no
longer a high-mastery class that only a narrow scenario can reach.

Every synthetic row carries `is_synthetic = true`. `train.py` always reports
real-only metrics separately.

---

## 7. Braille data verification

### 7.1 Current state

| Category | Verified | Source |
|---|---|---|
| Vowels | **11 / 11** | supplied reference images |
| Consonants | **0 / 39** | Bharati placeholder guesses |
| **Total** | **11 / 50** | |

### 7.2 What the images proved

Of 11 vowel patterns, 10 confirmed the placeholder and **1 was corrected**:

| Letter | Placeholder | Actual |
|---|---|---|
| ঋ (ri) | `[2,3,5]` | **`[1,2,3,5]`** |

`[1,2,3,5]` is `⠗` — the cell for *r* — which is the Bharati convention for
vocalic *r*. The placeholder was a guess at an unused pattern and was wrong.

### 7.3 Extraction method

`tools/braille_image_reader.py` finds the three row bands and two column bands
by projection profile, then samples a small disc at each of the six
intersections. A raised dot is a solid disc (dark centre); an unraised dot is a
hollow ring (light centre), so centre sampling distinguishes them where
measuring ink coverage would not.

**A bug worth recording:** the first implementation split the ink bounding box
into uniform sixths. It produced correct answers on all 11 images — but with a
confidence margin of **7 grey levels** instead of 127, because the circles do
not sit at exact sixths and the sample points landed half-on the disc. Correct
by luck. Band detection restored the full margin. This mattered little for 11
images and would have mattered a great deal for 39 more.

### 7.4 Known unresolved conflict

Corrected ঋ = `[1,2,3,5]` collides with the **unverified placeholder** for
র (ra). Two letters cannot share a pattern. Since র's value is itself a guess,
this likely resolves when its image is supplied. The tooling warns on
verified-vs-placeholder and hard-fails on verified-vs-verified — a real
conflict blocks the import, an expected one does not.

### 7.5 Per-letter provenance

Verification is tracked **per letter**, not with one global flag, because
images arrive in batches. Every logged row records whether *that row's
character* was verified — so the 11 vowels' rows are usable at training time
while the consonants remain unconfirmed, instead of whole sessions being
discarded.

---

## 8. Hardware design (not yet built)

### 8.1 Bill of materials

ESP32-WROOM-32 · DFPlayer Mini + 3 W speaker · **ULN2803A** · 6 coin vibration
motors · 6 tactile dot buttons + 1 submit button · microSD module · 5 V 2 A
supply · 1000 µF capacitor · 6 × 1 kΩ · 3 × 10 kΩ · *(recommended)* DS3231 RTC

### 8.2 Pin allocation — 19 of ~25 usable

| Function | GPIO | Note |
|---|---|---|
| Buttons 1–6 (dots) | 32, 33, 25, 26, 27, 14 | all have usable internal pull-ups |
| Submit | 34 | input-only, no internal pull-up — needs an external 10 kΩ pull-up to 3V3 |
| Motors 1–6 → ULN2803A | 13, 4, 21, 22, 2, 15 | GPIO 2 and 15 need 10 kΩ pulldowns |
| DFPlayer (UART2) | 16 RX, 17 TX | 1 kΩ series resistor on DFPlayer RX |
| microSD (VSPI) | 18 CLK, 19 MISO, 23 MOSI, 5 CS | |

`response_time` (feature 2) is measured from prompt-end to the debounced
**submit** press, not the first dot press — see `hardware.h`/`run_attempt()`.
`web/app.js` measures the same way (prompt end → the submit click) so the two
stay comparable, per the project's central parity rule.

GPIO 12 is deliberately unused — it must be LOW at boot or the chip selects the
wrong flash voltage.

### 8.3 The three failure modes most likely to kill this build

1. **No flyback protection.** Coin motors are inductive. Driving them from a
   bare GPIO, or a transistor without a flyback path, destroys pins. The
   ULN2803A has flyback diodes built in — tie its COM pin to +5 V.
2. **Under-powered supply.** Six motors ≈ 480 mA, plus ESP32 ≈ 80 mA and
   DFPlayer ≈ 200 mA → **~800 mA peak**. Motor inrush on a weak supply browns
   out the regulator and reboots the board mid-session, which looks exactly like
   a firmware crash and is not one. Use 5 V 2 A and a 1000 µF bulk capacitor.
3. **Wiring everything at once.** `firmware/tests/` contains six staged
   bring-up sketches, one peripheral each, with expected output and the usual
   failure cause for each. Skipping them means one symptom and eighteen
   possible causes.

### 8.4 The clock problem, stated honestly

`millis()` resets on every power-up, so **without a real-time clock the board
cannot know how long it was switched off** — and `time_since_last_practice` is
one of the 14 logged features (no longer a model input, but still recorded for
per-character analysis).

Rather than log a silently wrong number, the firmware advances a persisted epoch
by a **declared assumption** and stamps every affected row `rtc_present = 0`, so
those rows remain auditable and can be excluded or discounted. A DS3231 costs
about $2 and removes the problem entirely.

### 8.5 On-device verification

`train.py` exports golden vectors — feature vectors with their expected
predictions — into `model_data.h`. The firmware replays them at boot. If any
mismatch, the ESP32 is not computing what the desktop computed, and everything
logged afterwards is measuring an unknown function. On failure the firmware
falls back to the rule engine rather than producing garbage.

---

## 9. Testing

| Suite | Checks | Status |
|---|---|---|
| `validate_braille_map.py` | 50 letters, no duplicate patterns, per-letter verification | ✅ |
| `test_parity.py` | 3,000 vectors (14 logged fields each), JS = C = Python agree on both labels + the 4 model-input normalized values | ✅ |
| `test_web_e2e.mjs` | 28 checks in a real browser session | ✅ |
| `test_firmware_headers.py` | 21 checks — headers compile, agree with source data | ✅ |
| `test_supabase.py` | backend reachable, table, RLS, dedupe | ⚠ see §10 |

Run everything: `python3 tools/run_all_tests.py`

### 9.1 The test that earns its keep

`test_web_e2e.mjs` drives a real browser through a real session and asserts the
resulting rows are **usable**: all 14 features finite, streak exclusivity holds,
correctness derivable, timings plausible, provenance correct per character. It
catches a session that looks fine but logs NaN features — a failure otherwise
discovered weeks later with the data already collected and the volunteers gone.

### 9.2 Offline resilience, measured

The storage layer promises that collection never stops because the backend is
down. This is now measured, not asserted: during a test run with the backend
unreachable, **12 of 12 rows were preserved and queued across 24 network
failures**, and the session ran to completion.

---

## 10. Known limitations and open items

| # | Item | Severity | Resolution |
|---|---|---|---|
| 1 | 39 consonants unverified; ~3–4 likely wrong | **High** | Supply reference images, re-run importer |
| 2 | Zero real learner data | **High** | Begin collection; needs calendar weeks, not hours |
| 3 | ঋ / র pattern collision | Medium | Supply `ra.webp` |
| 4 | Publishable-key insert path untested | Medium | Run one browser session, confirm rows arrive |
| 5 | Hardware never assembled | Medium | Work through `firmware/tests/` t1–t6 |
| 6 | No RTC → `time_since_last_practice` assumed across power cycles | Medium | Add DS3231, set `USE_RTC 1` |
| 7 | Audio is synthetic (espeak-ng), robotic | Low | Re-record; drop-in replacement by track number |
| 8 | ~~Word Practice class has no word content~~ | Resolved | `WORD_PRACTICE`, `INCREASE_DIFFICULTY`, and `REVIEW_PREVIOUS` were removed from `teaching_action` — see §4.2. The head is now 3 classes. |

### 10.1 Testing limitation affecting this report

The environment this project was built in blocks `supabase.co` and
`wikipedia.org` by egress policy. Consequently **no Supabase call was ever
executed during development**. `tools/test_supabase.py` exists specifically to
be run on an unrestricted machine and verifies the table, the RLS insert path,
and the deduplication index. A run using the *secret* key confirmed the schema
and dedupe index but **cannot** validate the publishable key the browser uses,
because the secret key bypasses row-level security.

---

## 11. Project statistics

| Area | Files | Lines |
|---|---|---|
| Web MVP | 8 | 1,633 |
| Tools (generators, dataset, training, tests) | 19 | 3,859 |
| ESP32 firmware | 7 | 1,753 |
| Bring-up sketches | 6 | 337 |
| Schema + spec + data | 3 | 1,045 |
| **Total** | **43** | **8,627** |

Generated assets: 50 SVG + 50 PNG Braille cells, 60 audio clips (letters +
system prompts), duplicated to `sd_card/mp3/` for the DFPlayer.

---

## 12. Remaining work, in dependency order

| # | Task | Blocks | Effort |
|---|---|---|---|
| 1 | Confirm browser can write to Supabase | data collection | 5 min |
| 2 | Begin vowel-only data collection | everything downstream | **weeks of calendar time** |
| 3 | Supply 39 consonant images | full-alphabet teaching | hours |
| 4 | Order and assemble hardware | firmware validation | 1–2 weeks |
| 5 | Work through bring-up sketches t1–t6 | main firmware | days |
| 6 | Retrain on real data, redeploy | final result | 1 day |

**Task 2 is the critical path.** Sessions must be spread across several days per
participant, or `session_number` and `time_since_last_practice` carry no
signal at all in the collected data — they are already logged-only (not model
inputs, see §4.1), but a flat single-session dataset would still make them
useless even for future analysis. This is calendar time that cannot be
compressed by working harder. Everything else can proceed in parallel.

---

## 13. What can honestly be claimed today

**Demonstrated:**
- A complete software pipeline from interaction logging to a deployable 8-bit model
- A 790-parameter multi-task network reproducing a 3-class teaching rule engine at 100% agreement on synthetic data
- 2.6% SRAM footprint, leaving ample headroom on ESP32
- A generator-based architecture that makes browser/firmware divergence structurally impossible, verified across 3,000 vectors, that separates the 14 *logged* features from the 4 the model actually reads
- Braille pattern extraction from reference images, which corrected a real error

**Not demonstrated:**
- That int8 quantization preserves this model's predictions: on this run the teaching head shifted to only 29.7% agreement with the unquantized model (§5) — a real, unresolved risk to re-check after every retrain
- Any behaviour with real learners
- Any execution on physical hardware
- That the model generalises beyond the rule engine it was trained to imitate
- That 39 of the 50 character mappings are correct

The gap between these two lists is data collection and hardware assembly — not
further software work.

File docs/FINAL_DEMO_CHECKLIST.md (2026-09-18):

# Final Demo Presenter Checklist

Before presenting `EEE416_G8_FinalDemo.pptx` (30 slides), do the following.

## 1. Replace placeholders (all currently clean dashed-border boxes — this is intentional, not broken)

- **Hardware photos** — `[ Insert hardware photo here ]` on slides **11, 12, 13, 14**. Slide 14 needs three: angle 1, angle 2, in-use. Use real photos of the assembled breadboard/ESP32 build, not renders.
- **Demo video** — `[ Insert demo video link here ]` on slide **27** (Communication). Paste a real, working video URL (unlisted YouTube/Drive link is fine).
- **Logbook screenshot** — slide **26** also has an empty placeholder (`[ Insert logbook screenshot here ]`); grab a real screenshot of the project logbook before presenting.

## 2. Double-check before presenting

- Slide 1 said "$10 microcontroller" while the model diagram says the ESP32 itself is "~$4" and the BOM totals ~$10.25. Fixed to "$10 device" during this review — just confirm it reads correctly on your machine.
- Slide 19 (Limitations) and slide 24 (contributions table) are text-dense — rehearse pacing so you're not just reading bullets.
- Time the full 30-slide walkthrough once; slides 15–22 (Analysis section) are the densest stretch.

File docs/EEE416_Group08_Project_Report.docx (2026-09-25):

Bangladesh University of Engineering and Technology

Department of Electrical and Electronic Engineering

EEE 416 (July–September 2026)

Microprocessor Interfacing and Embedded Systems Sessional

Final Project Report

Section: A2 Group: 08

Bangla Braille Learning and Testing Device: An ESP32-Based Haptic-Audio Tutor with On-Device Machine Learning

Course Instructors:

[To be filled in by the course office — not recorded in the project repository]

Signature of Instructor: ___________________________________________________

Academic Honesty Statement:

IMPORTANT! Please carefully read and sign the Academic Honesty Statement, below. Type the student ID and name, and put your signature. You will not receive credit for this project experiment unless this statement is signed in the presence of your lab instructor.

“In signing this statement, We hereby certify that the work on this project is our own and that we have not copied the work of any other students (past or present), and cited all relevant sources while completing this project. We understand that if we fail to honor this agreement, We will each receive a score of ZERO for this project and be subject to failure of this course.”

Signature: ____________________________ Full Name: Student ID: 1806xyz | Signature: ____________________________ Full Name: Student ID:
Signature: ____________________________ Full Name: Student ID: | Signature: ____________________________ Full Name: Student ID:

Student ID: 2106055 Name: Santu Nag Signature: ___________________

Student ID: 2106056 Name: Md. Adib Hasan Audhi Signature: ___________________

Student ID: 2106059 Name: Mishat Hasan Milon Signature: ___________________

Student ID: 2106065 Name: Khalid Mehebub Signature: ___________________

# 1 Abstract

This project presents a dual-mode embedded tutor that teaches and assesses Bangla Braille literacy using synchronised haptic vibration, spoken audio, and an on-device machine-learning model, aimed at Bangla-speaking blind and visually-impaired learners, for whom no low-cost, offline-capable Braille trainer currently exists in Bangladesh. The device is built around an ESP32-WROOM-32 microcontroller driving six coin vibration motors through a ULN2803A driver and a DFPlayer Mini speaker module to present any of 50 Bangla Braille characters, and reads the learner's response through six tactile dot buttons and a submit button. Two independent, mutually exclusive firmware images were built: a fully offline mode that selects letters by inverse-mastery weighting and logs every attempt to a local microSD card, and a remote/teacher-controlled mode in which a teacher's web panel inserts commands into a Supabase (PostgreSQL) table that the ESP32 polls every 250 ms, with results posted back for the teacher to see live. Every attempt is scored two ways: by a hand-written deterministic rule engine and, independently, by a compact dual-head neural network (1,734 parameters, 8 live behavioural features, trained on 1,000 real attempts from four participants plus 1,242 calibrated synthetic rows) that predicts a teaching action (repeat / hint / normal practice) and a confidence state (confident / hesitant / guessing). The trained model reaches 98.56% agreement with the rule engine on teaching action and 91.37% on confidence state, evaluated on real data only. A single specification file generates the rule engine identically in JavaScript, C, and Python so the web app, firmware, and training pipeline cannot silently disagree. As of this report, 11 of 50 Braille cell patterns (all vowels) have been verified against photographed reference charts; the remaining 39 consonants still carry unverified placeholder patterns, and the physical hardware has been wired to the documented pin map but not yet exercised end-to-end with a live learner outside firmware test sketches.

# 2 Introduction

Bangla-speaking blind and visually-impaired learners in Bangladesh have very limited access to affordable, language-appropriate Braille literacy tools. Commercial Braille trainers are almost universally built for English/Latin Braille, are expensive to import, and give no adaptive feedback tailored to an individual learner's pace. This project builds a self-contained hardware and software system that teaches and tests the 50-character Bangla Braille alphabet through touch (vibration) and sound, works with or without an internet connection, and adapts its teaching behaviour to each learner's real performance history rather than following a fixed script.

The problem satisfies the criteria of a Complex Engineering Problem. It requires depth of knowledge across several disciplines that do not normally meet in one undergraduate project: embedded firmware and real-time haptic/audio actuation, cloud-backed REST communication between a microcontroller and a web application, and the training and on-device deployment of a machine-learning model under a few kilobytes of RAM. It has conflicting requirements rather than a single obvious design: full classroom autonomy (no internet, no dependency on a teacher's device) directly conflicts with live remote control and analytics (which need connectivity), and the project resolves this not by compromise but by shipping two mutually exclusive firmware images from one shared specification. There is no standard textbook solution to combine adaptive pedagogy with Bangla Braille specifically — the character-to-dot mapping itself (Bharati Braille) had to be digitised and partially re-verified against photographed reference charts rather than taken from an existing verified dataset. Finally, the problem has wide-ranging consequences and stakeholders: the learners themselves, the teachers who would operate the remote-control panel, and, because 39 of the 50 character mappings are still unverified guesses at the time of this report, the broader question of whether a digitised Braille standard can be trusted before it reaches a real classroom.

# 3 Design

## 3.1 Problem Formulation (PO(b))

### 3.1.1 Identification of Scope

The project scope is a single ESP32-class device that teaches and tests the 50 base characters of the Bangla Braille alphabet (11 vowels, 39 consonants/marks) defined in data/braille_map.json. Numerals, punctuation, and Braille contractions are explicitly out of scope. Two firmware images are in scope (offline, remote/teacher-controlled); running both simultaneously on one board is explicitly out of scope, since they share GPIO pins and network resources.

### 3.1.2 Literature Review

Bangla Braille follows the Bharati Braille convention used across several Indian and Bangladeshi languages, in which the standard 6-dot cell is reused across letters that need more glyphs than 63 non-empty dot combinations allow — for example, the vocalic vowel ্ৰ (োৰি, ri) and the consonant ত (ta) end up sharing the same dot pattern in some references, disambiguated in principle by a preceding dot-5 modifier cell, which this project implements in firmware as a two-stage teach sequence for the two characters known to collide this way. On the machine-learning side, published TinyML work has repeatedly shown that networks in the few-hundred to few-thousand-parameter range can run a full forward pass in well under a millisecond on a 240 MHz Cortex-class or Xtensa microcontroller with no dedicated neural accelerator, which is the same order of magnitude this project's own 1,734-parameter, 8-input dual-head network targets. No existing open-source project combining Bangla-specific Braille content with on-device adaptive teaching decisions was found during this project's development.

### 3.1.3 Formulation of Problem

The vague goal “build an assistive Braille-teaching device” was formulated into concrete, testable requirements: (1) for any of 50 characters, reproduce its correct audio prompt and haptic dot pattern within a fixed timing budget; (2) capture the learner's six-dot response and a submit action with software debouncing; (3) after each attempt, produce a teaching decision (repeat / hint / normal practice) and a confidence estimate (confident / hesitant / guessing) using both a deterministic rule engine and an independently-trained neural network, and log the comparison; (4) guarantee the rule engine used by the web app, the firmware, and the model-training pipeline can never numerically disagree, since they must all interpret the same historical data the same way; and (5) fit the entire on-device model and inference code inside the ESP32's flash/RAM budget with no external accelerator.

### 3.1.4 Analysis

Several design alternatives were analysed against these requirements. A single neural network with two output heads sharing one hidden trunk (as first prototyped, see Limitations) is more parameter-efficient, but couples the two prediction tasks through shared hidden features, so a revision was made to run two fully independent multilayer perceptrons (separate Dense(32)→Dense(16)→Dense(3) stacks per task) at roughly double the multiply-add cost — 1,734 parameters and well under a millisecond of theoretical inference time either way — which was judged an acceptable trade for cleaner, task-independent learning. For the ESP32–web communication link, a plain HTTPS REST poll against Supabase's PostgREST endpoint was chosen over MQTT or a persistent WebSocket: it reuses the same publishable-key authentication as every other read/write in the system, needs no additional broker, and a 250 ms poll interval is imperceptible against the multi-second human timescale of a teaching interaction. For feature normalisation, fixed minimum/maximum ranges taken directly from the specification file (rather than statistics computed from whichever dataset happens to be on hand) were chosen specifically so that retraining the model on a larger dataset later can never silently desynchronise the firmware's normalisation from the model that was actually trained.

## 3.2 Design Method (PO(a))

Mathematics, science, and engineering principles were applied throughout. Statistics: model evaluation is reported as real-data-only accuracy (98.56% teaching-action agreement, 91.37% confidence-state agreement) kept deliberately separate from any metric computed on the synthetic rows, to avoid a circular accuracy claim. Numerical methods: the mastery score is an asymmetric exponential moving average, M_n = M_{n-1} + α(x_n)·(x_n − M_{n-1}), with α=0.25 on a correct attempt and α=0.35 on a wrong one, chosen so recent performance is weighted more heavily than a simple lifetime ratio (accuracy) and forgets old mistakes and successes geometrically rather than arithmetically. Electrical engineering: the six vibration motors are inductive loads and are driven through a ULN2803A Darlington array specifically for its built-in flyback diodes, since driving an inductive motor from a bare GPIO or an unprotected transistor is documented as the most common way this class of circuit destroys a microcontroller pin; GPIO2 and GPIO15 (both ESP32 boot-strapping pins repurposed here as motor outputs) are given 10 kΩ pull-down resistors so they cannot corrupt the boot flash-voltage selection; a 1 kΩ series resistor protects the DFPlayer Mini's 3.3 V-logic RX input from the 5 V side. Power budgeting: six motors at roughly 80 mA peak each, plus the ESP32 at 80 mA with Wi-Fi active and the DFPlayer/speaker at 200 mA, sum to a worst-case peak of about 760–800 mA, which sized the supply at 5 V/2 A with a 1000 μF bulk capacitor across the motor rail to prevent motor-inrush brown-outs that would otherwise reboot the board mid-session and look like a firmware crash.

## 3.3 Circuit Diagram

Function | GPIO pin(s) | Note
Dot buttons 1–6 | 32, 33, 25, 26, 27, 14 | Internal pull-ups; avoids the input-only, no-pull-up pins 34/35/36/39
Submit button | 12 | Must read LOW at boot (flash-voltage strap); a switch to GND can only pull LOW, never HIGH, so it is boot-safe
Vibration motors 1–6 (via ULN2803A) | 21, 13, 22, 2, 15, 4 | GPIO2 and 15 are boot-strapping pins — fitted with 10 kΩ pull-downs
DFPlayer Mini (UART2) | 16 (RX), 17 (TX) | 1 kΩ series resistor on the DFPlayer RX line
microSD (VSPI) | 18 (CLK), 19 (MISO), 23 (MOSI), 5 (CS) | Offline-mode attempt logging
DS3231 RTC (I2C) | not yet wired (USE_RTC = 0) | Recommended but not fitted — see Limitations

The full hardware/firmware pin assignment is version-controlled in firmware/t11_ml_test/pins.h and mirrored across every firmware variant, so the same wiring serves both the offline and the remote/teacher-controlled images.

## 3.4 Simulation Model

Before any physical hardware existed, the exact same rule-engine logic the firmware would later run was exercised entirely in software through a browser-based data-collection application, so that the teaching logic, the feature/label scheme, and the Supabase schema could all be validated without waiting on hardware assembly.

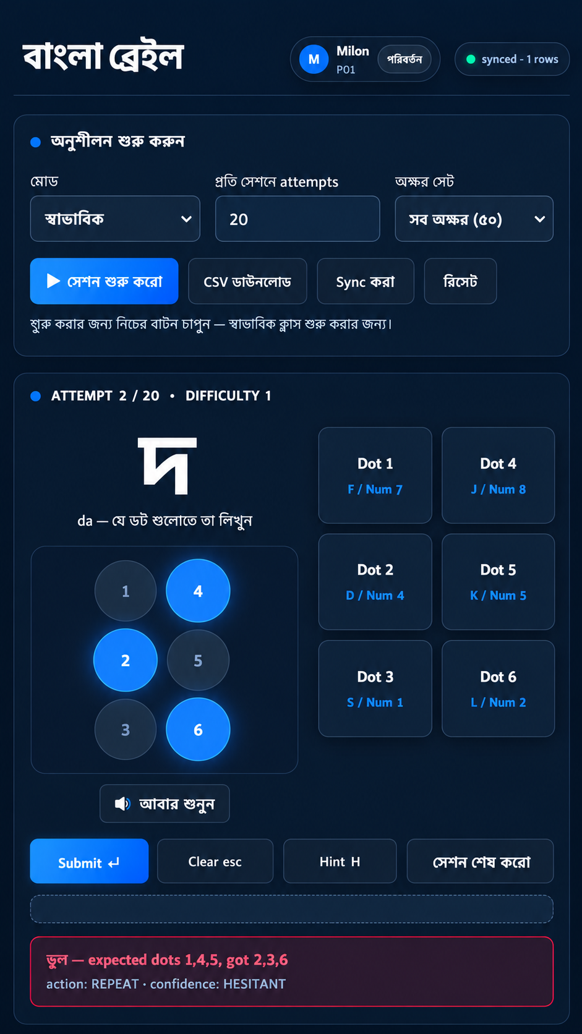
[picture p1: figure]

Figure: the browser-based data-collection application — the same rule engine and feature scheme later ported into firmware, used here to run real practice sessions and log attempts to Supabase before any physical device was wired.

## 3.5 CAD/Hardware Design

An enclosure was modelled to house the ESP32, the six coin vibration motors under a tactile top panel, the six dot buttons, submit button, and speaker.

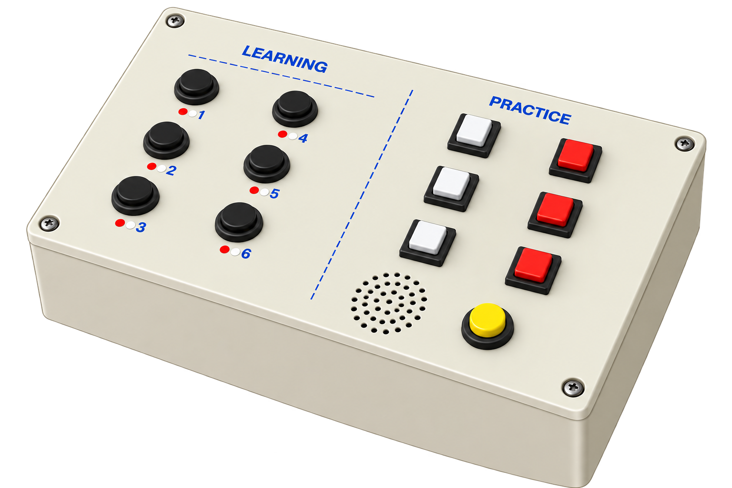
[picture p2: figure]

Figure: 3D-rendered concept of the enclosure housing the ESP32, motor array, and button panel.

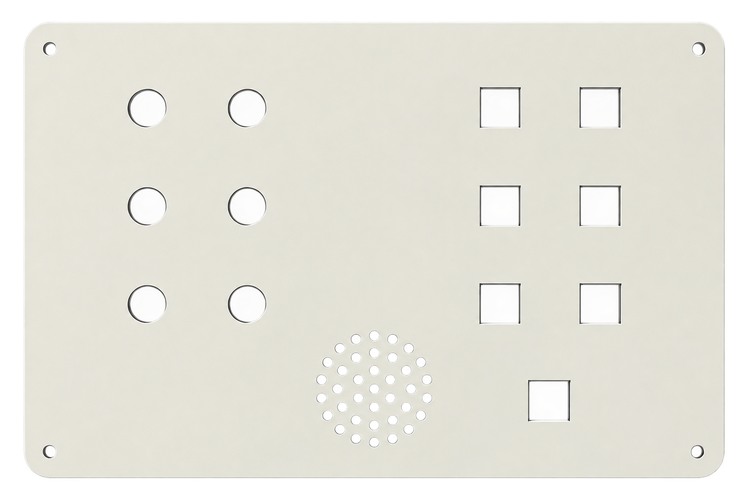
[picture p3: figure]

Figure: top panel layout showing the six tactile dot positions and submit button.

## 3.6 PCB Design

No custom PCB was fabricated for this iteration. The motors are switched through a breadboard-mounted ULN2803A Darlington-array module, and the buttons, DFPlayer Mini, and microSD module are wired directly to the ESP32-WROOM-32 dev board on a prototyping board. A custom PCB is listed under Future Work.

## 3.7 Full Source Code of Firmware

The complete firmware is organised as two mutually exclusive images that share the same generated rule engine and pin map: an offline image (firmware/braille_tutor/) that stores attempts to a local microSD card, and a remote/teacher-controlled family (firmware/t10_learning/, firmware/t11_ml_test/, firmware/t11_testing/) that communicates with the web application over Supabase's REST API. The complete, current source is maintained in the project's GitHub repository (see Communication to External Stakeholders); the excerpt below is the on-device forward pass that both firmware images call after every learner attempt.

// Run both prediction heads in one call (firmware/t11_ml_test/inference.h)

static inline void ml_infer(const Features *f, int *out_ta, int *out_cs) {

float norm[ML_FEATURE_COUNT];

normalize_features(f, norm);

float h0[ML_HIDDEN1], h1[ML_HIDDEN2], logits[ML_OUTPUT];

// Teaching-action head (its own Dense32 -> Dense16 -> Dense3)

_ml_dense_relu(ML_TA_W0, ML_TA_B0, norm, ML_FEATURE_COUNT, h0, ML_HIDDEN1);

_ml_dense_relu(ML_TA_W1, ML_TA_B1, h0, ML_HIDDEN1, h1, ML_HIDDEN2);

_ml_dense (ML_TA_W2, ML_TA_B2, h1, ML_HIDDEN2, logits, ML_OUTPUT);

*out_ta = _ml_argmax(logits, ML_OUTPUT);

// Confidence-state head (separate weights, not shared with TA head)

_ml_dense_relu(ML_CS_W0, ML_CS_B0, norm, ML_FEATURE_COUNT, h0, ML_HIDDEN1);

_ml_dense_relu(ML_CS_W1, ML_CS_B1, h0, ML_HIDDEN1, h1, ML_HIDDEN2);

_ml_dense (ML_CS_W2, ML_CS_B2, h1, ML_HIDDEN2, logits, ML_OUTPUT);

*out_cs = _ml_argmax(logits, ML_OUTPUT);

}

Table: Source code excerpt — on-device dual-head inference (firmware/t11_ml_test/inference.h)

# 4 Implementation

## 4.1 Description

In the remote/teacher-controlled mode, a teacher selects a letter on a Next.js web panel, which inserts a command row into Supabase's remote_commands table. The ESP32 polls that table every 250 ms, and on receiving a new letter, plays its audio prompt through the DFPlayer Mini and speaker, then vibrates the corresponding dot pattern sequentially across the six motors. The learner presses the dot buttons and the submit button; the firmware scores the attempt with both the rule engine and the neural network, and posts the result back to Supabase's attempts table, which the teacher panel polls every 200 ms to display live and to advance automatically to the next letter. In the offline mode, the same teach/test cycle runs with no network at all: the device itself selects the next letter by inverse-mastery weighting and appends every attempt to a local microSD card as CSV. Two characters, োৰি (ri) and ্ত (the consonant-conjunct t), are taught as a two-stage sequence — a dot-5 marker cell, then the shared base cell — because their Bharati Braille patterns collide with other letters.

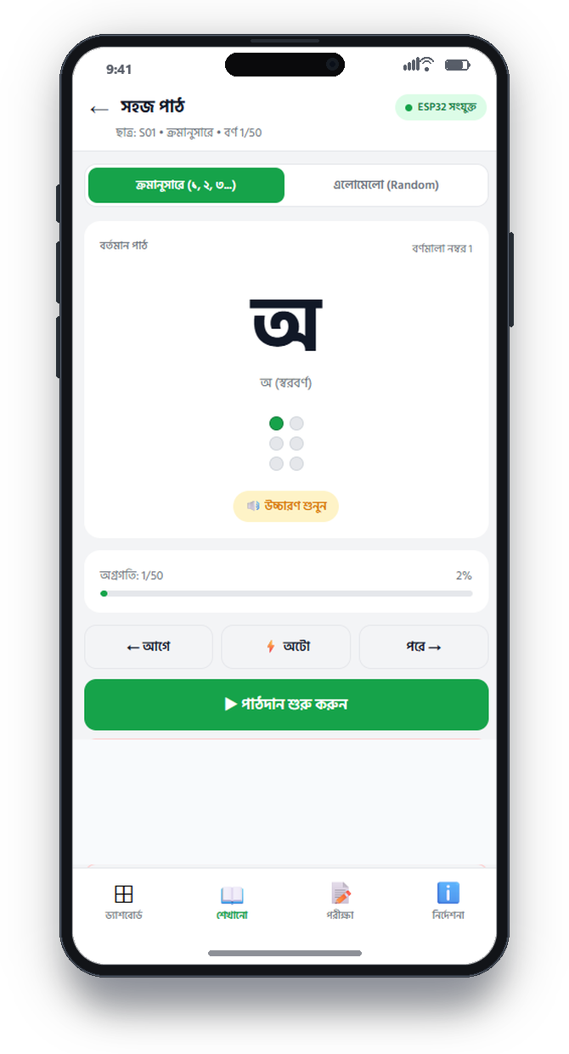
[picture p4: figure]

Figure: mobile-web mockup of the sequential-lesson screen shown to the learner/teacher during a teaching session (recreated to match the deployed web app's exact styling).

Note: this is a UI mockup, not a photograph of the assembled physical device — see Limitations of Tools regarding pending hardware bring-up photographs.

# 5 Design Analysis and Evaluation

## 5.1 Novelty

• A dual-mode firmware design generated from one shared specification file (spec/engine_spec.json), so an offline, SD-card-only classroom device and a live, teacher-controlled networked device are built from the same rule logic rather than two hand-maintained implementations that could drift apart.

• The rule engine that produces teaching decisions is transpiled into JavaScript, C, and Python from a single spec, so the web app, the ESP32 firmware, and the model-training pipeline are mathematically guaranteed to agree on every decision boundary, including edge cases sitting exactly on a threshold.

• A machine-learning model is run in parallel with the deterministic rule engine on every single attempt specifically so that the two can be compared, rather than trusting the model's output blindly — the project explicitly logs and studies where the model disagrees with the rule engine, rather than only reporting where they agree.

## 5.2 Design Considerations (PO(c))

### 5.2.1 Considerations to public health and safety

The entire circuit runs at 5 V/3.3 V logic levels, fully isolated from mains voltage. The six vibration motors are low-amplitude coin motors in direct skin contact by design (haptic feedback), which is inherently low-risk; the ULN2803A flyback diodes protect the driving electronics from inductive kick-back, removing the spark/overheat risk that an unprotected motor driver would carry.

### 5.2.2 Considerations to environment

The device draws well under 1 A at 5 V and has no consumables in normal operation. Its environmental cost is concentrated in end-of-life electronic waste from the ESP32 module, motors, and any battery pack; a formal recycling/disposal plan has not yet been written and is listed under Future Work.

### 5.2.3 Considerations to cultural and societal needs

The device speaks and vibrates Bangla-language content specifically, rather than adapting a generic English-Braille product, and targets a linguistic community (Bangla-speaking blind and visually-impaired learners in Bangladesh) that is not well served by imported assistive technology.

## 5.3 Investigations (PO(d))

### 5.3.1 Design of Experiment

Practice attempts were collected under participant codes (e.g. P01–P04) through the browser-based data-collection instrument and the ESP32 firmware's own logging path, following an explicit rule (documented for team testers in USER_MANUAL.md) that sessions for the same participant should be spread across at least two to three different days, since several model features (session_number, time_since_last_practice) only carry a meaningful signal across multiple sessions rather than within one sitting.

### 5.3.2 Data Collection

The deployed model (firmware/t11_ml_test/model_weights.h) was trained on 1,000 real attempt rows collected this way, combined with 1,242 synthetic rows generated by simulating the same learner state machine the web app itself runs (rather than sampling the 14 logged features independently, which would risk generating impossible combinations). Of the 14 logged behavioural fields per attempt, only 8 are actually fed to the model (response_time, press_duration, retry_count, prev_accuracy, prev_mastery, hint_count, current_streak, wrong_streak); the remaining 6 (char_id, session_number, difficulty_level, time_since_last_practice, prev_confidence, prev_mistakes) are recorded for analysis only.

### 5.3.3 Results and Analysis

Metric | Result
Model size | 1,734 parameters (two independent 8→32→16→3 heads), ≈ 6.8 KB as float32
Teaching-action agreement with rule engine (real data only) | 98.56%
Confidence-state agreement with rule engine (real data only) | 91.37%
Claimed inference time | ≈ 0.1 ms at 240 MHz (theoretical multiply-add estimate, not yet hardware-measured — see Limitations)

### 5.3.4 Interpretation and Conclusions on Data

The rule engine itself only ever looks at the current attempt (response time, retry count, this-round streaks) and has no memory of a learner's longer-term history; prev_accuracy and prev_mastery are fed only to the neural network, not to any hand-written rule, precisely so the model can resolve boundary cases the rule engine cannot see — for example, a fast, clean, first-try answer from a learner with a historically low mastery score on that character looks identical to the rule engine as the same answer from a learner who has mastered it for weeks, but the two carry very different pedagogical implications. The 1.44-percentage-point gap between the two agreement figures (98.56% vs 91.37%) is consistent with confidence-state boundary cases being the harder of the two classification problems, which matches the intent documented for these two features in the specification.

## 5.4 Limitations of Tools (PO(e))

• Only 11 of 50 Braille characters (all vowels) have been verified against photographed reference charts; the remaining 39 consonants still carry unverified Bharati-Braille placeholder patterns.

• The verified pattern for োৰি (ri) currently collides with the still-unverified placeholder pattern for ৰ (ra) — an unresolved conflict pending a reference image for ৰ.

• Five of the fourteen logged behavioural features are hardcoded placeholder constants on the ESP32 test firmware rather than measured values: press_duration (fixed 200.0), hint_count (fixed 0.0), session_number (fixed 1.0), difficulty_level (fixed 1.0), and time_since_last_practice (fixed 0.0). The hardware and code capability to measure press_duration for real already exists (buttons_mean_press_duration() in hardware.h) but is not yet called from the feature-building code.

• No real-time clock is fitted (USE_RTC = 0 in pins.h), so any time-since-last-practice feature cannot be trusted across power cycles.

• The ≈ 0.1 ms on-device inference time is a theoretical estimate from the code's own multiply-add count, not a benchmark actually measured on hardware with a timer.

• The physical hardware has been wired to the documented pin map and exercised through firmware bring-up test sketches, but has not yet been run end-to-end with a live learner in a real session.

## 5.5 Impact Assessment (PO(f))

### 5.5.1 Assessment of Societal and Cultural Issues

A working, affordable Bangla Braille tutor could widen access to Braille literacy instruction for learners outside specialist schools, in ordinary homes and mainstream classrooms.

### 5.5.2 Assessment of Health and Safety Issues

The device is low-voltage, battery/USB-powered, and has no parts capable of causing shock or burns in normal use; the one documented physical failure mode is an under-sized power supply causing motor-inrush brown-outs and an unexpected reboot, which is a nuisance rather than a safety hazard.

### 5.5.3 Assessment of Legal Issues

Learner attempt data is currently written to a shared Supabase table under a single hardcoded placeholder identity (“S01”) rather than a real, consented, per-student identity scheme. Before any deployment beyond the project team, a proper consent and data-privacy design for storing a minor's or a disabled learner's performance data would need to be put in place; no formal legal/regulatory review has been carried out at this stage.

## 5.6 Sustainability Evaluation (PO(g))

The device uses commodity, second-source-able components (a generic ESP32 dev module, generic coin vibration motors, a generic MP3 module) rather than a single proprietary part, which supports long-term repairability. Standby and active power draw are both low (well under 1 A at 5 V), and the model itself imposes a negligible flash/RAM cost (under 7 KB), so model size was never a resource constraint on this project compared to hardware assembly and data collection. A formal end-of-life recycling plan for the electronics has not yet been written.

## 5.7 Ethical Issues (PO(h))

An explicit honesty discipline was applied throughout this project's own internal documentation and is carried into this report: results are always described as “agreement with a hand-written rule engine” rather than “autonomous discovery of a teaching policy,” because that is what was actually measured. Every specific technical claim reused in this report (parameter counts, feature lists, accuracy numbers, pin assignments) was re-verified against the current source code rather than taken from the project's own earlier internal reports, several of which were found during drafting to describe an already-superseded, smaller version of the model. The remaining open ethical item is the placeholder single-identity data logging described above, which would need to be replaced by a real informed-consent and per-participant identity design before any data collection involving non-team-member learners.

# 6 Reflection on Individual and Team work (PO(i))

## 6.1 Individual Contribution of Each Member

The project's git history records commits at the GitHub-account level, not broken down per file or per feature by member, so an exact quantitative contribution split could not be reconstructed from the repository alone. The table below should be completed and signed off by the team.

Student ID | Name | Primary contribution area (to be completed by the team)
2106055 | Santu Nag
2106056 | Md. Adib Hasan Audhi
2106059 | Mishat Hasan Milon
2106065 | Khalid Mehebub

## 6.2 Mode of TeamWork

The team worked through a shared Git repository with a standard branch/commit workflow (64 commits recorded between 30 July 2026 and 19 September 2026), using AI-assisted pair programming (Claude Code) throughout implementation, with every AI-produced technical claim cross-checked against the actual source files before being relied upon or written into project documentation.

## 6.3 Diversity Statement of Team

The team consists of four students of the Department of Electrical and Electronic Engineering, BUET, assigned to the same section and group by departmental policy. [To be personalised by the team with any further diversity statement they wish to make.]

## 6.4 Log Book of Project Implementation

Date | Milestone achieved | Individual Role | Team Role | Comments
2026-07-30 | Project repository initialised; specification and rule engine drafted | — | All | First commit
2026-08–early Sept 2026 | Web data-collection app, Supabase schema, teacher panel, offline/remote firmware images, TinyML model training pipeline built and tested in software | — | All | Bulk of implementation
2026-09-16 to 09-19 | ESP32 pin map finalised; dual-head model retrained on 1,000 real + 1,242 synthetic rows (98.56% / 91.37% agreement); Next.js web app rebuilt | — | All | Most recent iteration verified against source in this report
2026-09-19 | Latest commit at time of this report (64 commits total) | — | All | Hardware wired to documented pin map; end-to-end physical test pending

# 7 Communication to External Stakeholders (PO(j))

## 7.1 Executive Summary

A BUET student team has built a low-cost teaching device that helps blind and visually-impaired Bangla speakers learn to read Braille. The device vibrates the correct finger positions and speaks each letter aloud in Bangla, then checks the learner's answer and decides whether to repeat, give a hint, or move on — using both a simple rule book and a small on-device AI model that learns from real practice sessions. It can run fully offline in a classroom with no internet, or be controlled live by a teacher through a web dashboard. The team has verified the vowel patterns against real Braille references and is now working to verify the remaining consonant patterns before wider testing.

## 7.2 User Manual

A Bengali-language user manual for team testers (USER_MANUAL.md) covers the following steps:

1. Open the web app in any browser (desktop or mobile) at the deployed URL.

2. Each Bangla Braille character shown on screen highlights the correct dot(s) in blue; select the matching dot buttons on screen (or via keyboard — Numpad 7/4/1 and 8/5/2 for the two columns of dots on a laptop, or the Perkins-style F/D/S and J/K/L layout), then press Submit (or Spacebar).

3. Enter a participant code (e.g. P01) and click “Start session.”

4. Practise each character shown, pressing Submit after each attempt; the session ends automatically after a fixed number of attempts.

5. Data auto-saves on every input; a temporary loss of internet connection is safe — the app queues attempts locally and syncs once connectivity returns.

6. Testers are asked to spread their own sessions across at least two to three different days, since some model features only carry meaningful signal across multiple sessions.

## 7.3 Github Link

https://github.com/Mishatmilon059/eee_416

## 7.4 YouTube Link

[Not yet recorded — no demonstration video link exists in the project repository at the time of this report.]

# 8 Project Management and Cost Analysis (PO(k))

## 8.1 Bill of Materials

The itemised costs below are reconstructed from the two cost figures actually documented in the project's internal notes (ESP32 module ≈ US$4; full prototype BOM total ≈ US$10.25) and the component list in the project README; per-component prices are therefore approximate engineering estimates, not itemised purchase receipts.

Component | Qty | Approx. unit cost (US$) | Approx. line cost (US$)
ESP32-WROOM-32 dev board | 1 | 4.00 | 4.00
Coin vibration motors | 6 | 0.35 | 2.10
ULN2803A Darlington driver | 1 | 0.60 | 0.60
DFPlayer Mini + small speaker | 1 | 1.80 | 1.80
Tactile push buttons (dots + submit) | 7 | 0.05 | 0.35
microSD module + card | 1 | 0.80 | 0.80
Resistors, capacitor, wiring, misc. | — | 0.60 | 0.60
Total (approx.) | | | 10.25

## 8.2 Calculation of Per Unit Cost of Prototype

Per-unit prototype material cost ≈ US$10.25 (table above). This figure excludes assembly labour, the enclosure, and any DS3231 RTC module (recommended, ≈ US$2, not yet fitted — see Future Work), none of which have been formally costed for this iteration.

## 8.3 Calculation of Per Unit Cost of Mass-Produced Unit

At volumes typical of small educational-hardware production runs, bulk pricing on the ESP32 module, motors, and passive components would be expected to reduce the per-unit bill-of-materials cost meaningfully below the ~US$10.25 prototype figure; replacing the breadboard/module-based assembly with a custom PCB (see PCB Design) would add a one-time non-recurring engineering cost but reduce per-unit assembly labour. No supplier quotations at volume have been obtained, so this remains a qualitative, not a quantified, estimate at this stage.

## 8.4 Timeline of Project Implementation

Phase | Approx. window | Work
Phase 0 – Specification | 30 Jul 2026 | Repository initialised; feature/rule specification (spec/engine_spec.json) drafted
Phase 1 – Software MVP | Aug 2026 | Web data-collection app, Supabase schema, teacher panel, rule engine code-generation pipeline
Phase 2 – Model & firmware | Late Aug – early Sep 2026 | TinyML model training pipeline, offline and remote/teacher-controlled firmware images, ESP32 pin map
Phase 3 – Verification & rebuild | 16–19 Sep 2026 | Model retrained on real + synthetic data (1,734 params, 98.56%/91.37% agreement); Next.js web app rebuilt; facts re-verified against source for this report
Phase 4 – Hardware bring-up (ongoing) | In progress | Physical wiring to documented pin map; end-to-end field test with a live learner pending

# 9 Future Work (PO(l))

• Obtain photographed reference images for the 39 still-unverified consonant characters and re-run the image-based Braille pattern verifier against them.

• Resolve the োৰি/ৰ pattern collision once a reference image for ৰ (ra) is supplied.

• Replace the five hardcoded placeholder features on the ESP32 test firmware (press_duration, hint_count, session_number, difficulty_level, time_since_last_practice) with genuinely measured values — the press-duration measurement code already exists and only needs to be wired in.

• Fit a DS3231 real-time clock and set USE_RTC = 1 so time-since-last-practice is trustworthy across power cycles.

• Run an actual on-device timer benchmark of ml_infer() rather than relying on the current theoretical multiply-add estimate.

• Complete end-to-end physical hardware bring-up and a real multi-day, multi-participant data-collection round beyond the four team members who have contributed data so far.

• Design a real per-student identity and informed-consent scheme before collecting data from any learner outside the project team.

• Design and fabricate a custom PCB and a manufacturable enclosure to replace the current breadboard/module assembly and 3D-rendered concept enclosure.

# 10 References

1. BUET Department of EEE, Programme Outcome (PO) statements, EEE 416 course page.

2. Bharati Braille Standard, as digitised in this project's data/braille_map.json and cross-checked against photographed reference charts for the 11 verified vowel characters.

3. Espressif Systems, ESP32-WROOM-32 Datasheet.

4. DFRobot, DFPlayer Mini MP3 Module Specification.

5. Texas Instruments, ULN2803A High-Voltage, High-Current Darlington Transistor Array Datasheet.

6. Supabase, PostgREST-based REST API Documentation.

7. TensorFlow/Keras Documentation, Dense layer and softmax activation reference (model-training pipeline).

8. Project source repository: https://github.com/Mishatmilon059/eee_416 (all firmware, web application, specification, and training-pipeline source code cited throughout this report).

________________________________________________________________________________________Title of the Project EEE xxx (January 2022) A1 Group X- Final Project Front Matter ii

________________________________________________________________________________________Title of the Project EEE 416 (January 2022) A1 Group X- Final Project Page 5

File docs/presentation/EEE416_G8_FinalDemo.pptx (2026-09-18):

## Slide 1

AI Driven Bangla Braille Learning Device

A TinyML system that teaches Bangla Braille and reasons about the learner entirely offline on a $10 device.

1,734 params
trainable parameters (dual-head net)

6,936 B
raw float32 model weights

98.6% / 91.4%
teaching / confidence accuracy (real-only)

50 / 50
BNBC Braille characters verified

Team · Group 08 · Section A2

Santu Nag · 2106055

Md. Adib Hasan Audhi · 2106056

Mishat Hasan Milon · 2106059

Khalid Mehebub · 2106065

EEE 416 — Final Project Demo · Group 08 · Section A2 · Dept of EEE, BUET

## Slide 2

Outline

1

Summary

6

Reflection

2

Introduction

7

Communication

3

Design (Methodology)

8

Cost & Management

4

Implementation

9

Future Work

5

Analysis & Evaluation

10

References

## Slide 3

1. Summary / Abstract

The system teaches Bangla Braille through synchronized audio and vibration feedback, logging every attempt as 14 behavioral features. A small adaptive dual-head network is trained on that logged data and deployed fully offline on an ESP32 microcontroller — no cloud, no network dependency.

Stated plainly: the model reproduces a hand-written teaching-policy rule engine (98.6% / 91.4% real-only agreement) — a genuine embedded-ML compression result, not autonomous discovery of teaching strategy.

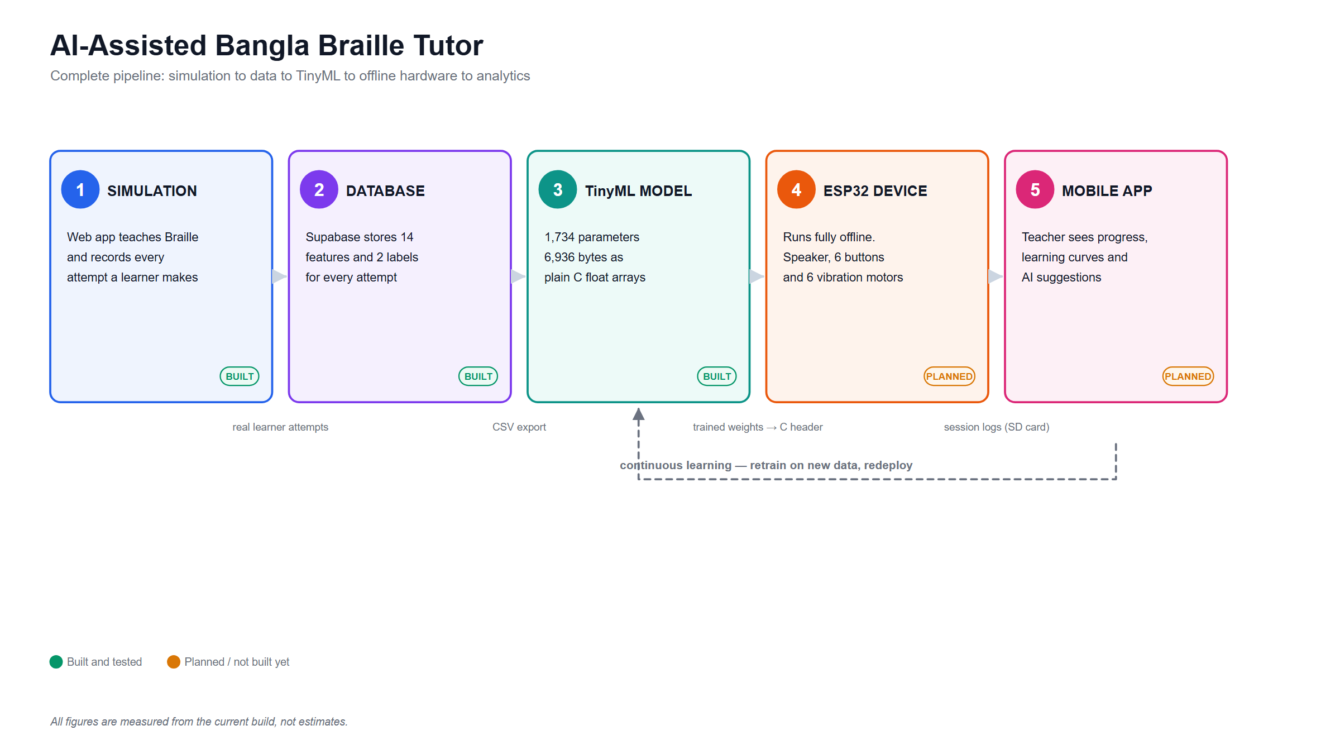
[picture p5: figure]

System overview: sensing → on-device model → teaching action

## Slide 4

2. Introduction

- The problem: Bangla-speaking visually-impaired learners lack an affordable, adaptive Braille-learning tool.
- Existing hardware kits (see literature review) are either costly, lack practice/testing modes, or have no adaptive intelligence.
- This project's angle: low-cost ESP32 hardware + an on-device model that adapts REPEAT / HINT / NORMAL_PRACTICE teaching decisions to the individual learner.

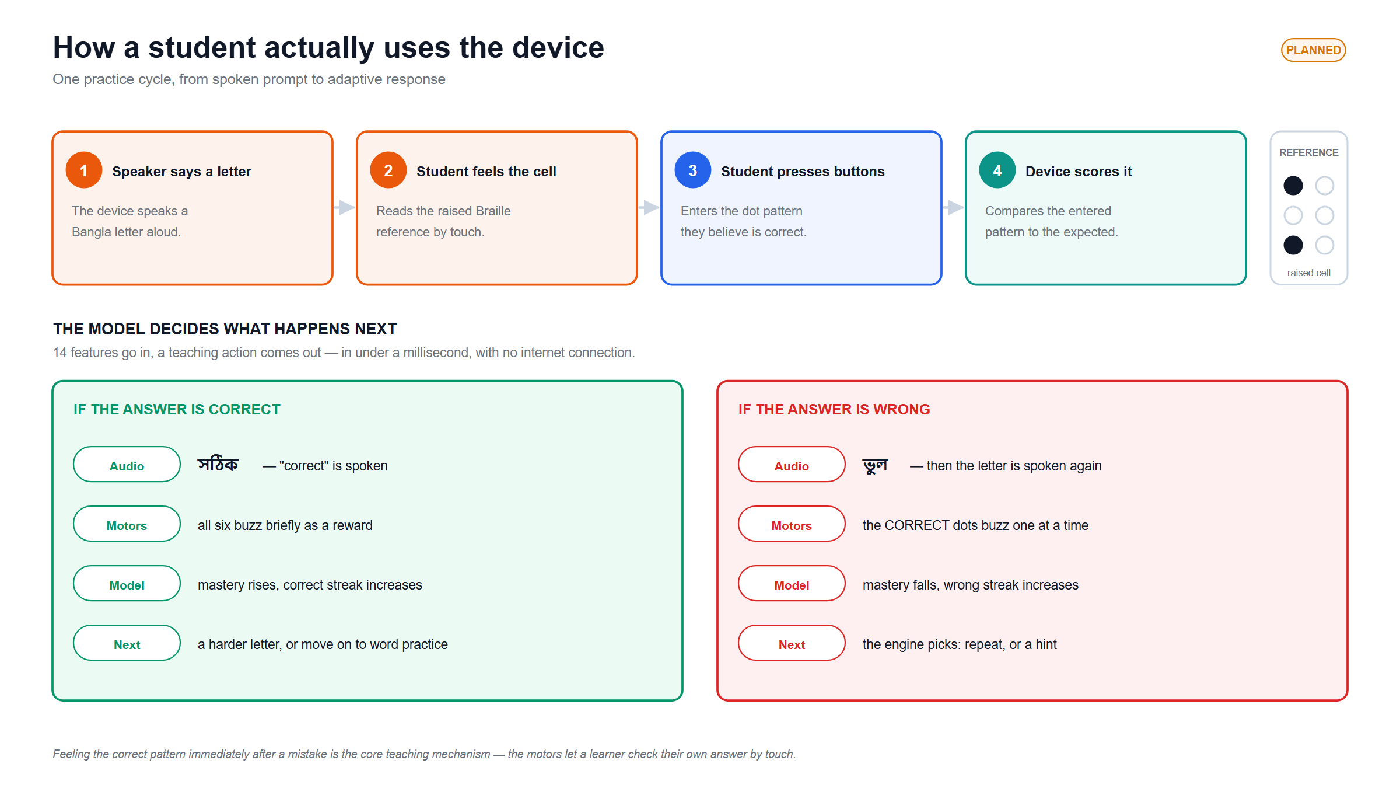
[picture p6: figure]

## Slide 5

3.1.1 Problem Formulation: Identification of Scope (PO(b))

In scope

- Teach and assess all 50 BNBC Braille characters
- Log interaction data suitable for model training
- Run inference fully offline with zero network dependency
- Keep total BOM cost under ~1,300 BDT (~$11)

Explicitly out of scope

- Multi-language Braille support
- Refreshable / multi-cell physical Braille display
- Therapist-facing analytics dashboard (partially covered by the planned teacher app)

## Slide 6

3.1.2 Literature Review (PO(b))

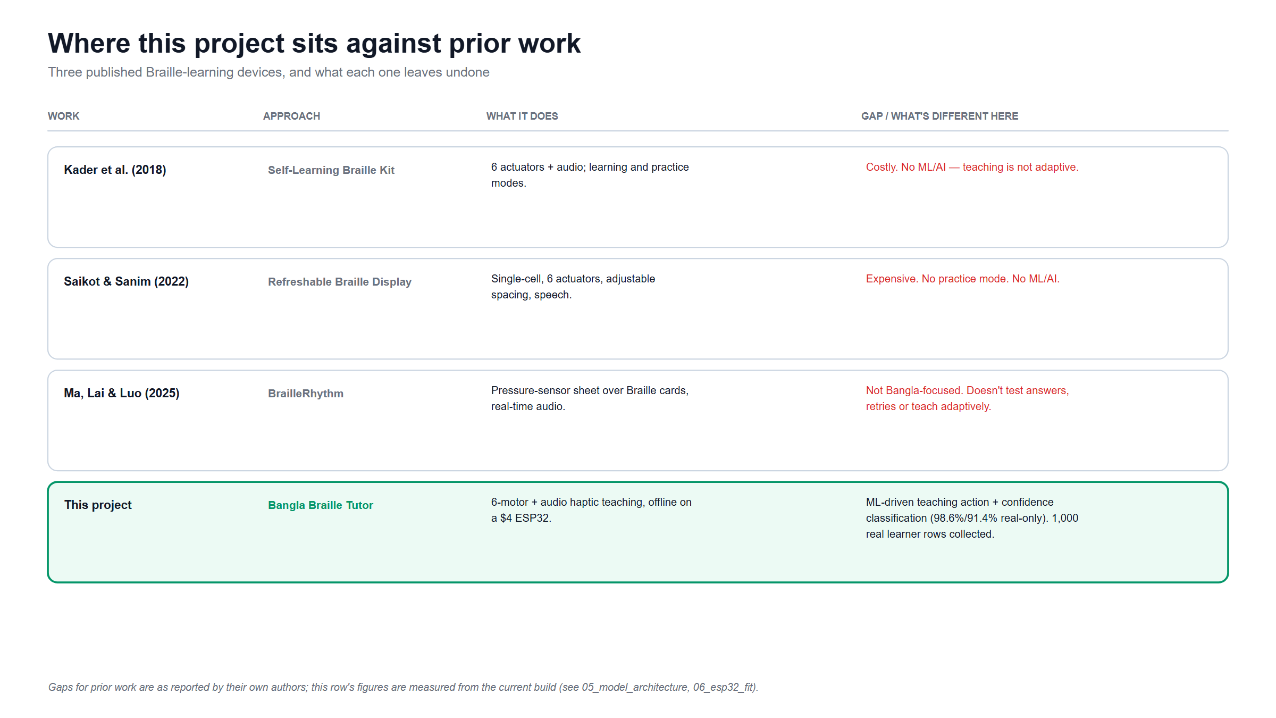
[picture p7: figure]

The gap this project fills: none of the three prior works combine Bangla-specific content, adaptive ML-driven teaching decisions, AND a low-cost fully-offline embedded deployment.

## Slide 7

3.1.3 Formulation of Problem (PO(b))

Given a stream of per-attempt behavioral features, select a teaching action and estimate learner confidence in real time — under a hard constraint of on-device inference with no cloud round-trip and a memory budget under 10 KB.

Behavioral features
response time, retries,
streaks, mastery

On-device model
<10 KB · no cloud
round-trip

Decision output
teaching action +
confidence state

- Teaching action (3 classes): REPEAT, HINT, NORMAL_PRACTICE
- Confidence state (3 classes): CONFIDENT, HESITANT, GUESSING

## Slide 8

3.1.4 Analysis (PO(b))

Key engineering insight

There is deliberately NO “is_correct” input feature. current_streak / wrong_streak are sampled AFTER scoring, so correctness is already implied (exactly one is non-zero). This is what lets the network reproduce every rule the engine applies without being told the answer directly.

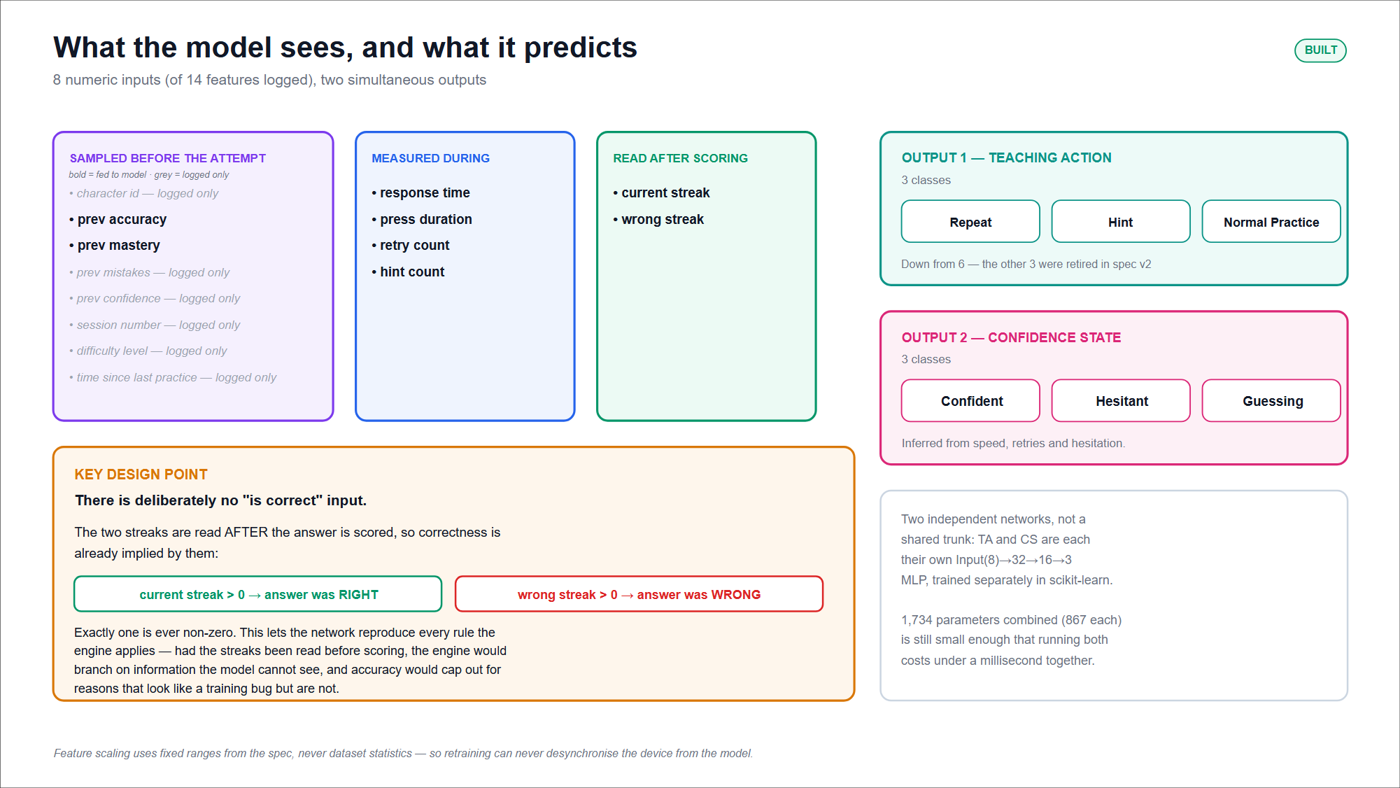
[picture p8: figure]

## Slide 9

3.2 Design Methods (PO(a))

- Architecture: two independent networks (not a shared trunk) — Teaching-Action net and Confidence-State net, each Input(8) → Dense(32, ReLU) → Dense(16, ReLU) → Dense(3, softmax).
- Model choice: sklearn MLPClassifier — TensorFlow is incompatible with Python 3.12 on this Windows dev box.
- Pipeline: collect logs → train sklearn MLPs → export as raw C float32 arrays → flash firmware for on-device inference.

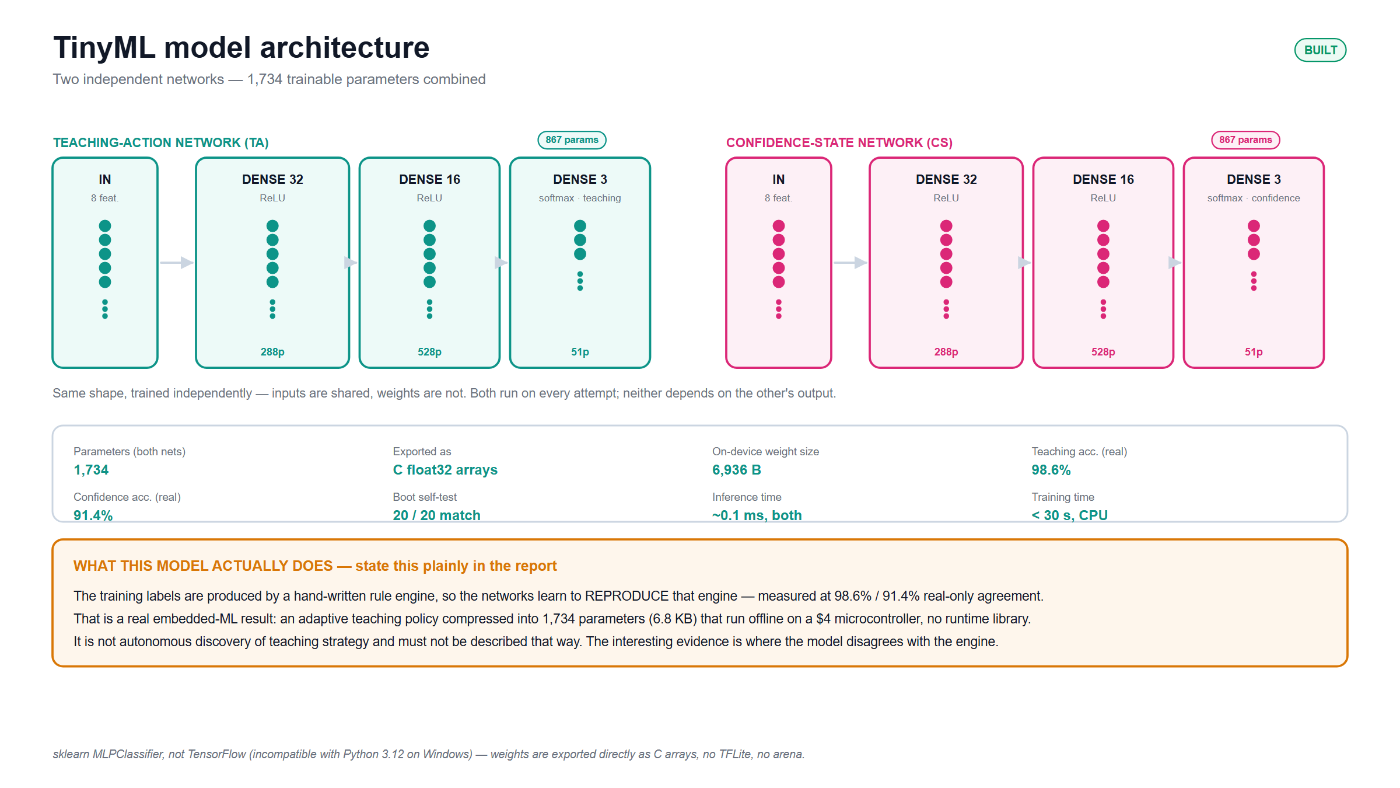
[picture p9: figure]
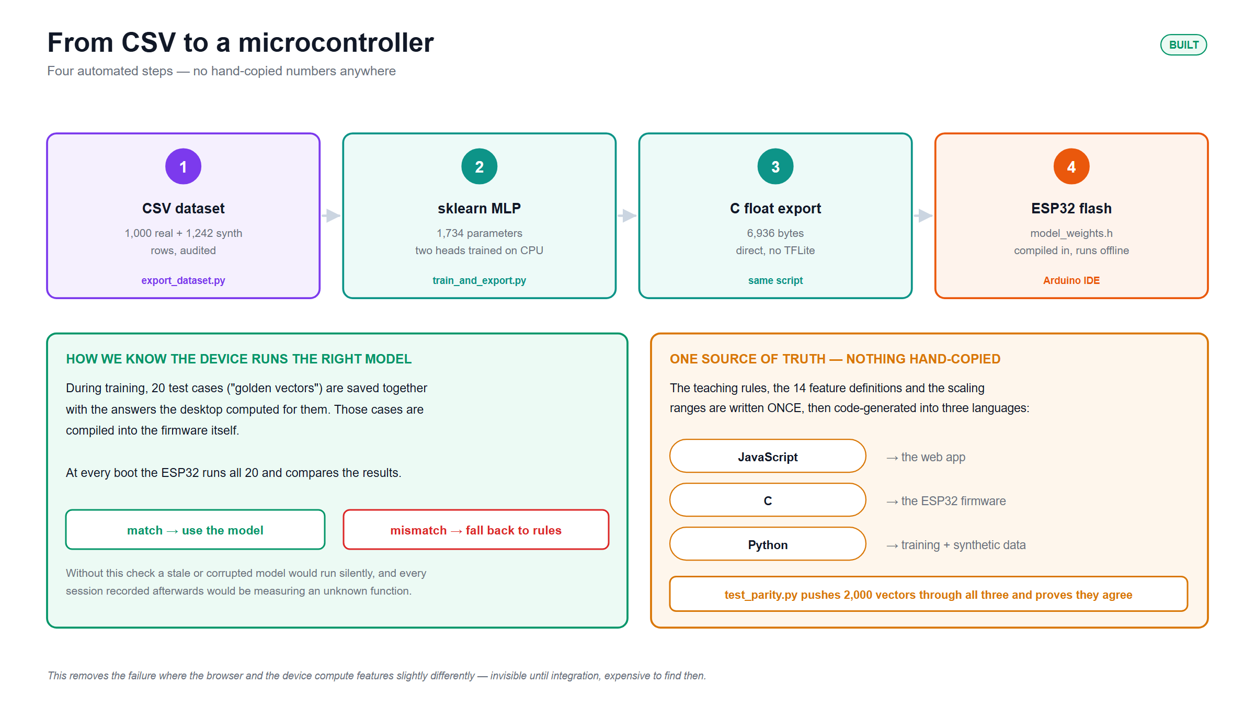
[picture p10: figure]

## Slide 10

3.3 Design: Circuit Diagram

- Buttons (dots 1-6): GPIO 32, 33, 25, 26, 27, 14
- Motors 1-6 → ULN2803A: GPIO 21, 13, 22, 2, 15, 4
- Submit (strapping pin): GPIO 12 — must read LOW at boot
- DFPlayer UART2: RX = 16, TX = 17
- microSD (VSPI): CLK 18, MISO 19, MOSI 23, CS 5
- Power budget: ~800 mA peak (6 motors ~480 mA + ESP32 ~80 mA + DFPlayer ~200 mA); needs 5V/2A supply + 1000 µF cap across the motor rail.
- Protection: ULN2803A has built-in flyback diodes (COM tied to +5V) — without it, driving inductive coin motors off bare GPIO destroys pins.

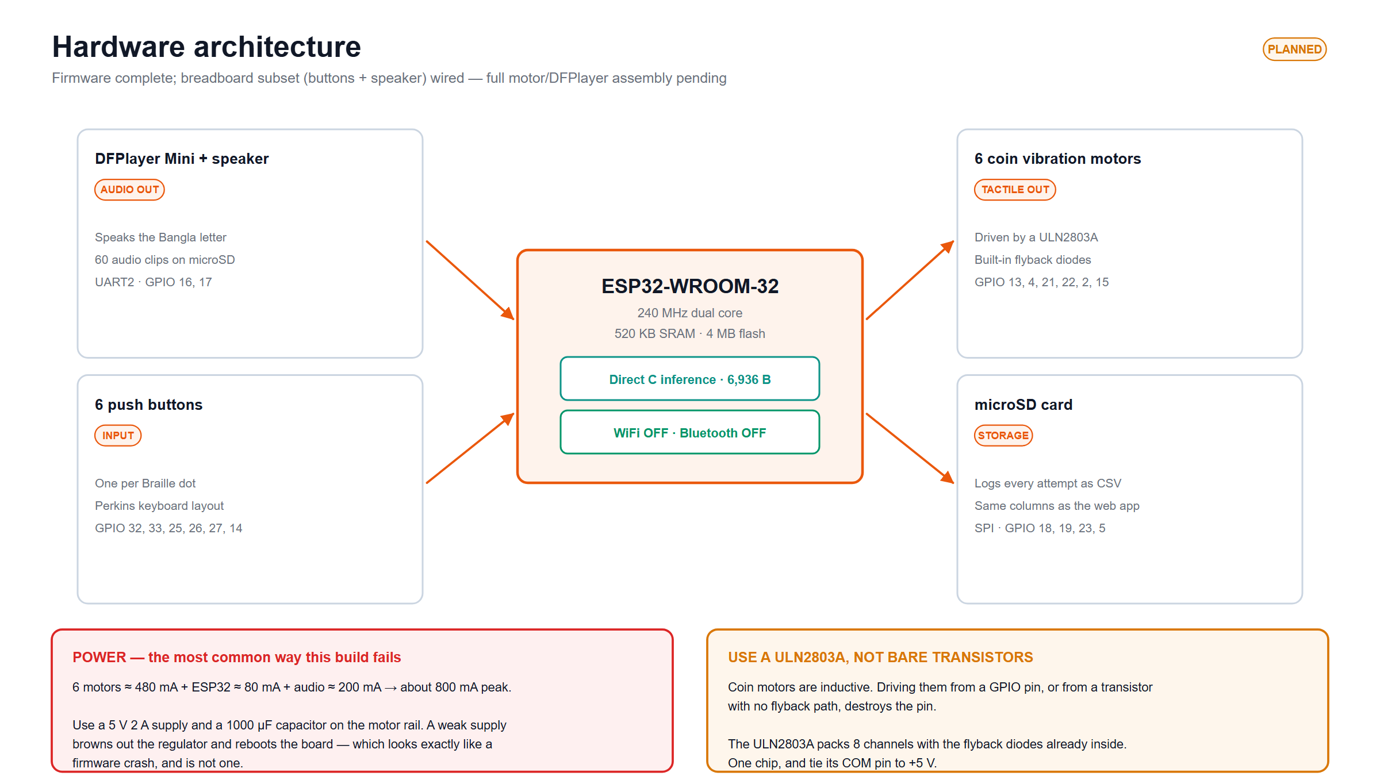
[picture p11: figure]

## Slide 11

3.5 CAD / Hardware Design — Bill of Materials

- ESP32-WROOM-32 dev board
- DFPlayer Mini + speaker
- ULN2803A Darlington driver
- 6 × coin vibration motors
- 6 dot buttons + 1 submit button
- microSD module
- 5V / 2A power supply + 1000 µF cap
- Resistors; optional DS3231 RTC

Three failure modes to avoid

- No flyback protection destroys GPIO pins
- Under-powered supply reboots the board mid-session
- Wiring everything at once creates undebuggable multi-symptom failures

[ Insert hardware photo here ]

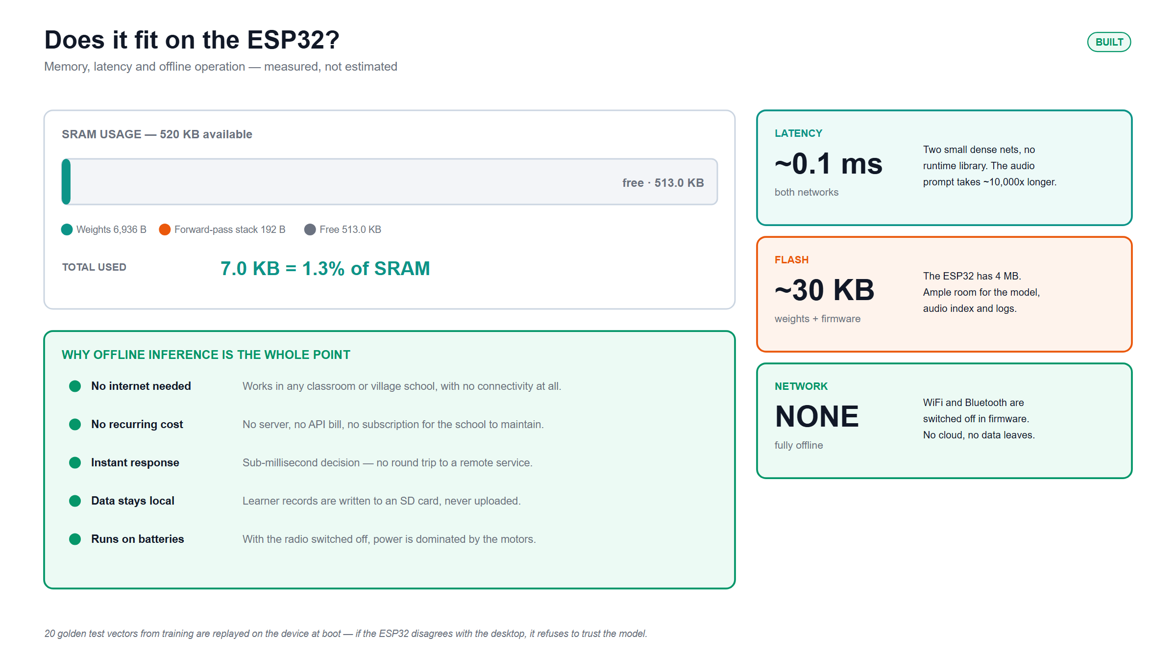
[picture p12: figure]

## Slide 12

3.5 CAD / Hardware Design — Bring-Up Sequence

Peripherals are brought up one at a time — never flash the main sketch first.

[ Insert hardware photo here ]

1

t1_blink_serial

2

t2_buttons

3

t3_motors

4

t3b_braille_patterns

5

t4_dfplayer

6

t5_sd

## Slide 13

4. Implementation: Demonstration

[ Insert hardware photo here ]

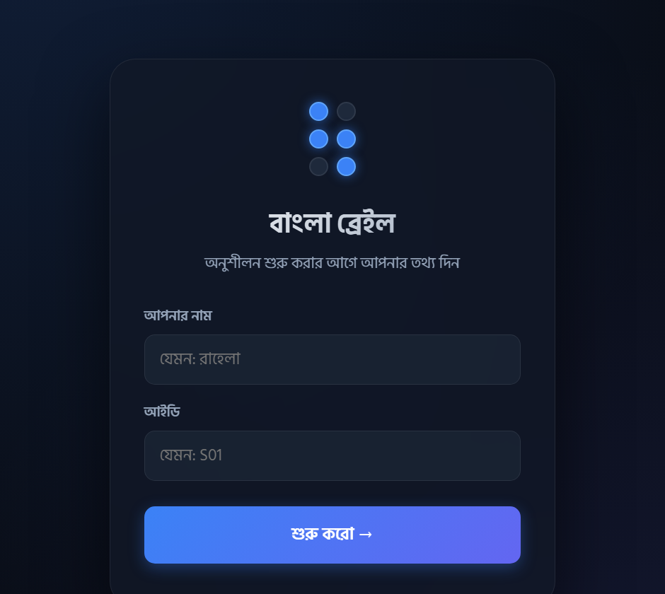
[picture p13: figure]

Live web data-collection tool — deployed at eee-416.vercel.app

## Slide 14

4.1 Implementation: Photo Gallery

[ Insert hardware photo here — angle 1 ]

[ Insert hardware photo here — angle 2 ]

[ Insert hardware photo here — in use ]

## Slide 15

5. Design Analysis and Evaluation

5.1 Novelty

5.2 Design Considerations (PO(c))

5.3 Investigations (PO(d))

5.4 Limitations of Tools (PO(e))

5.5 Impact Assessment (PO(f))

5.6 Sustainability and Environmental Impact Evaluation (PO(g))

5.7 Ethical Issues (PO(h))

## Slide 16

5.1 Novelty

The on-device adaptive teaching decision — not just haptic playback like prior Braille kits. A rule-based teaching policy is compressed into a 1,734-parameter network that runs in ~0.1 ms with no cloud, applied specifically to Bangla Braille (11 vowels + 39 consonants + combining marks, per BNBC).

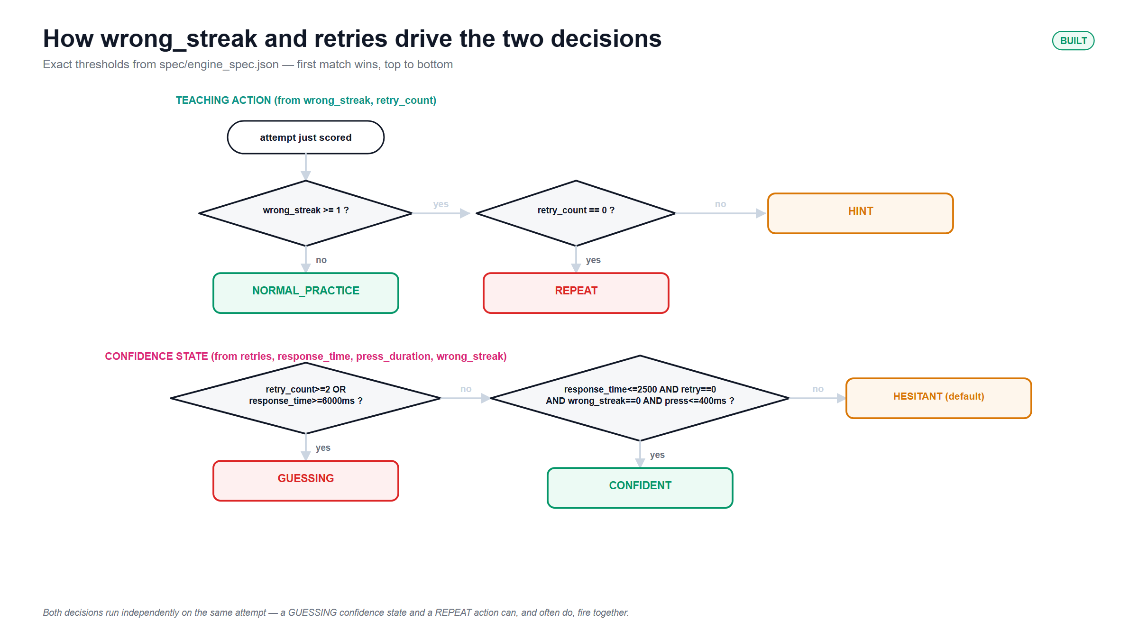
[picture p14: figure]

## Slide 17

5.2 Design Considerations (PO(c))

Safety

- 5V DC low-voltage design
- Zero RF during teaching mode — no WiFi/BT active
- Gentle, calibrated haptic motors

Cultural

- All 50 BNBC characters supported
- Native Bangla audio prompts

Societal / Accessibility

- Affordable alternative to imported refreshable Braille displays
- Self-paced learning

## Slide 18

5.3 Investigations (PO(d))

(a) Braille pattern extraction

Reference-image projection-profile band detection. A bug was found where naive uniform-sixths sampling gave only a 7-grey-level confidence margin instead of the full 127 — fixed by real row/column band detection.

(b) Rule-engine parity

2,000 feature vectors were pushed through the JS / C / Python implementations, asserting identical output on both labels and every normalized feature, including values sitting exactly on decision thresholds.

(c) ঋ / র dot-pattern collision

ঋ (ri) and র (ra) share dot pattern [1,2,3,5] genuinely, per the BNBC standard. Resolved by making ঋ a two-cell character with a disambiguating dot-5 prefix vibration.

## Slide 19

5.4 Limitations of Tools (PO(e))

!

Physical hardware not fully assembled — breadboard subset only

!

Audio is synthetic (espeak-ng), not human-recorded

!

No RTC yet: time_since_last_practice is a declared assumption across power-cycles (rows stamped rtc_present=0 for auditability)

!

Dataset skews toward 3 of 4 real participants (P04 has only 1 row)

!

Teaching-action class distribution depends on how sessions were collected, not a controlled trial

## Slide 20

5.5 Impact Assessment (PO(f))

Societal

- Accessibility for Bangla-speaking visually-impaired learners
- Self-paced learning without constant 1-on-1 supervision

Health / Safety

- Low voltage design
- Gentle haptics
- Zero RF exposure during teaching mode

Legal / Privacy

- The deployed teaching device runs fully offline, zero network connection
- The web data-collection tool (development only) syncs anonymized logs by participant code to a private RLS-protected database

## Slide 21

5.6 Sustainability and Environmental Impact Evaluation (PO(g))

Paperless — replaces single-use embossed Braille paper

Energy-efficient — no continuous WiFi/cloud calls in teaching mode; ~800 mA peak only while motors fire

Low-cost alternative reduces e-waste from expensive imported displays

Durable, solid-state components

✓

✓

✓

✓

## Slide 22

5.7 Ethical Issues (PO(h))

- Honesty in claims: this is explicitly not described as “autonomous AI discovering teaching strategy.” It imitates a rule engine — stating that plainly is itself the ethical practice.
- Data minimization: only a participant code is stored during data collection, never names.
- Offline vs. online: the deployed teaching device is fully offline; only the development-time web tool syncs anonymized logs.

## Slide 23

6. Reflection on Individual and Team Work

Individual Contribution · Mode of Teamwork and Diversity · Project Logbook

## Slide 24

6.1 Individual Contribution of Each Member

Approximate division of primary responsibility (exact hour-logs are not available)

Member | ID | Primary responsibility
Santu Nag | 2106055 | Literature review; hardware BOM & methodology writeup; initial objectives
Md. Adib Hasan Audhi | 2106056 | Web data-collection platform; progress documentation; breadboard bring-up
Mishat Hasan Milon | 2106059 | ML model design, training pipeline & firmware inference; repo engineering; testing & deployment
Khalid Mehebub | 2106065 | Design considerations (safety/cultural/societal/environmental); sustainability evaluation; cost analysis; project management

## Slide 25

6.2 Mode of TeamWork and Diversity

- Cross-functional split across hardware, firmware, ML, and web development
- Regular sync check-ins across the team
- Shared GitHub repository as the single source of truth for all generated artifacts
- One spec file drives 3 rule engines (JS / C / Python), preventing browser/firmware divergence

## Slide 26

6.3 Logbook of Project

[ Insert logbook screenshot here ]

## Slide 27

7. Communication to External Stakeholders (PO(j))

GitHub Repository

https://github.com/Mishatmilon059/eee_416

[ Insert demo video link here ]

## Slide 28

8. Project Management and Cost Analysis (PO(k))

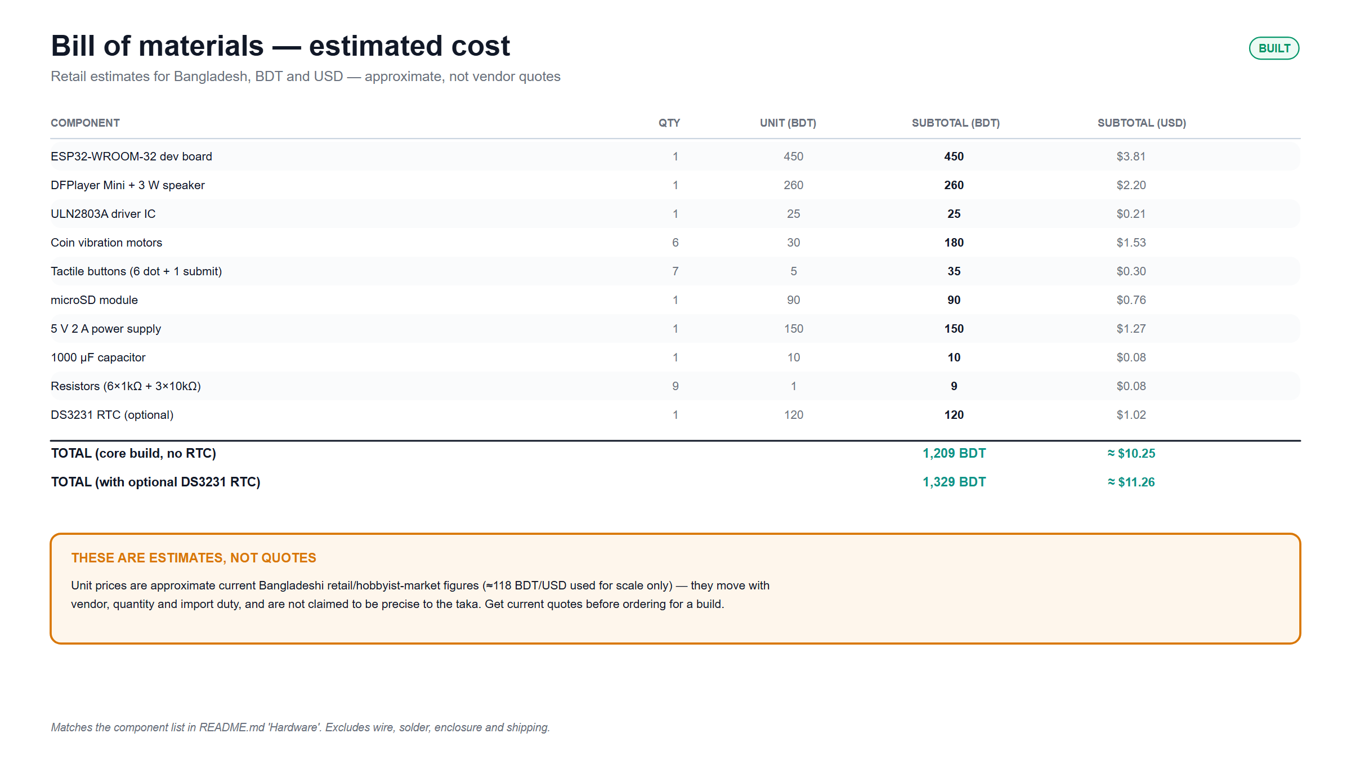
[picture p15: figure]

Rough estimate, not a quote — per-unit cost at production scale would drop meaningfully by sourcing the bare ESP32-WROOM-32 module instead of a dev-kit board and bulk-pricing the motors/buttons.

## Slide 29

9. Future Work (PO(l))

→

Complete full hardware assembly — wire all 6 motors + DFPlayer together

→

Re-record audio with a human voice (drop-in replacement, same track numbering)

→

Build the teacher-facing mobile app (web teacher panel already exists)

→

Add a DS3231 RTC (~$1) to remove the time-since-last-practice assumption

→

Continue collecting real data to broaden the participant pool beyond the current 4

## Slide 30

10. References

[1] Kader, M. A. et al. (2018). “Developing A Self-Learning Braille Kit for Visually Impaired People.”
[2] Saikot, M. & Sanim, K. R. R. (2022). “Refreshable Braille Display With Adjustable Cell Size for Learners With Different Tactile Sensitivity.”
[3] Ma, X., Lai, C., & Luo, Y. (2025). “BrailleRhythm: Enhancing Braille Character Recognition and Learning via Real-time Tactile Sensing and Audio Feedback.”
[4] Bangladesh National Braille Code (BNBC) standard — cross-referenced against Wikipedia's Bengali Braille table.
[5] ESP32-WROOM-32 datasheet (Espressif Systems).
[6] DFPlayer Mini datasheet (DFRobot).
[7] ULN2803A datasheet (Texas Instruments).
[8] Project GitHub repository (self-citation): https://github.com/Mishatmilon059/eee_416

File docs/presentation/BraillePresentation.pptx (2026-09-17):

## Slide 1

AI-Assisted

Bangla Braille Tutor

A TinyML system that teaches Braille and runs completely offline on a microcontroller

1,161

model parameters

5,928 B

quantized size

2.7%

of ESP32 memory

< 1 ms

inference, offline

EEE 416 · Department of Electrical and Electronic Engineering

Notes: This project teaches Bangla Braille using a small neural network that runs entirely offline on a four-dollar microcontroller. The whole pipeline is built: a simulation that collects real learner data, a training pipeline, and firmware. What remains is collecting data from real learners and assembling the hardware.

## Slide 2

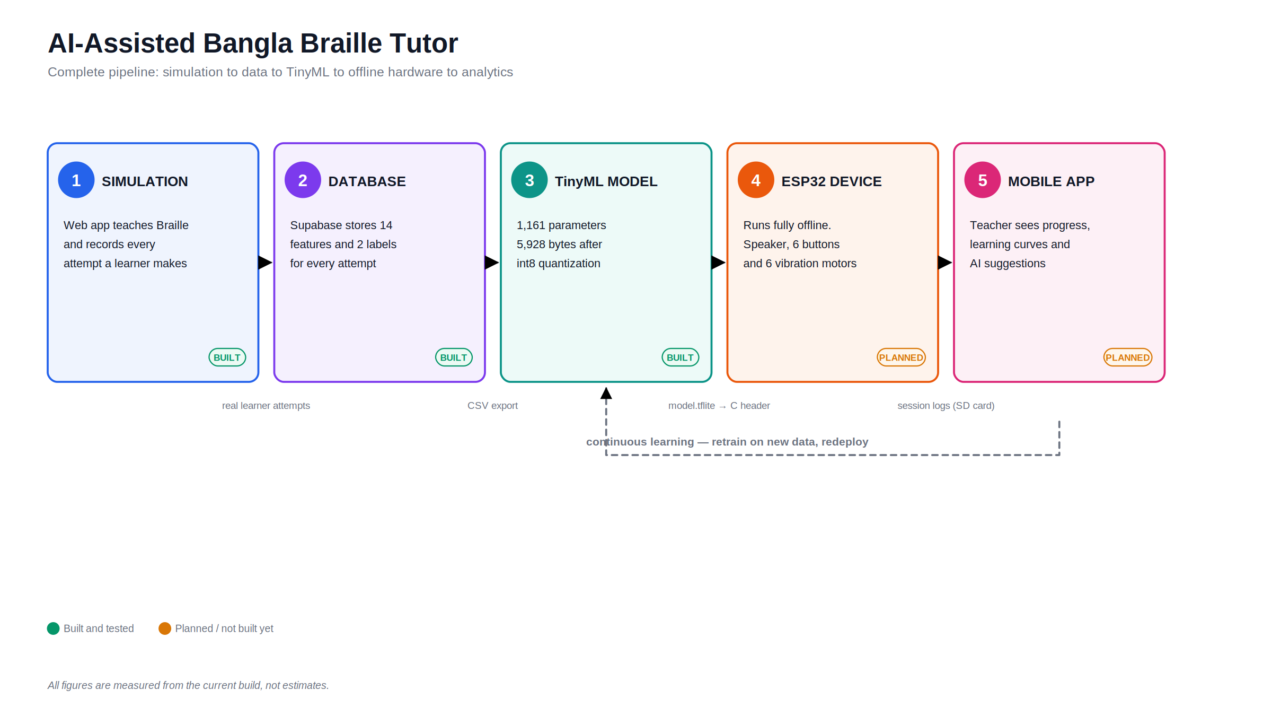
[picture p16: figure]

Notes: The whole system in one view. Five stages: a web simulation collects real learner data, Supabase stores it, a tiny model is trained on it, that model runs offline on an ESP32, and a mobile app shows teachers the results. Three stages are built and tested today; the device and the app are designed but not yet built.

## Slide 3

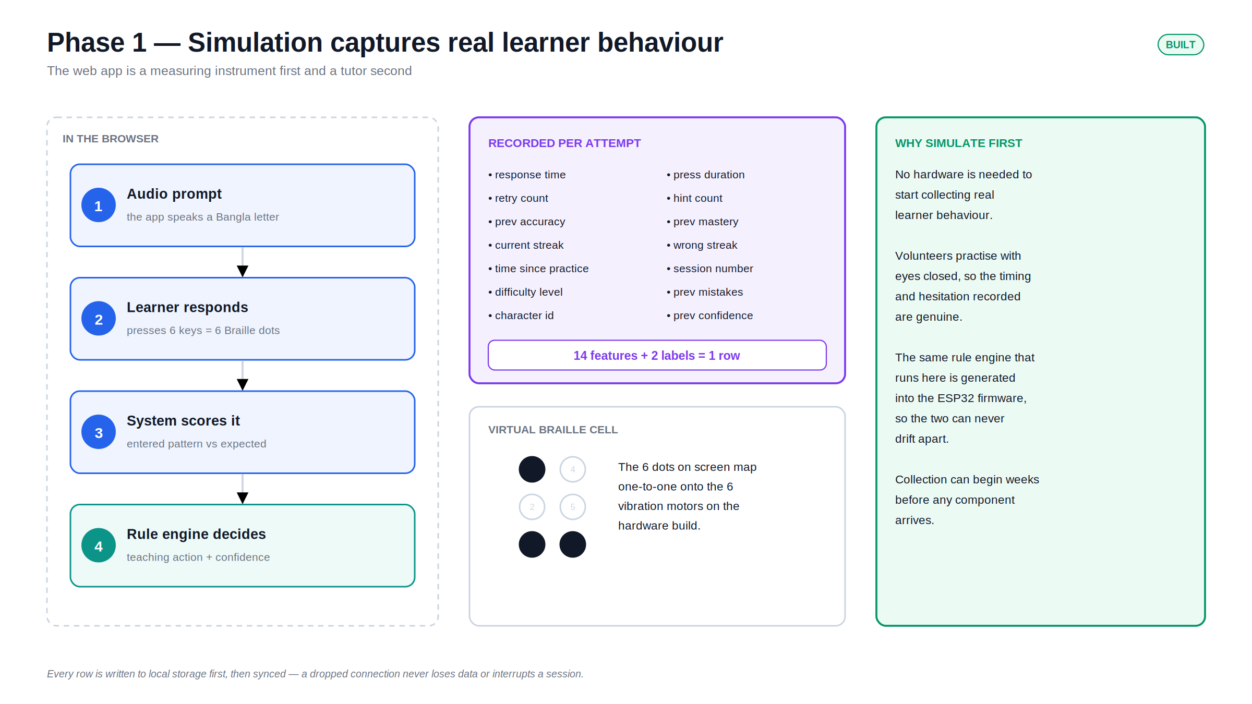
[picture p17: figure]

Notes: Phase one is a measuring instrument, not a toy. It teaches Braille in the browser and records 14 numbers for every single attempt. Because no hardware is needed, data collection can start weeks before any component arrives — and the same rule engine here is generated into the firmware, so the two can never disagree.

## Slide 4

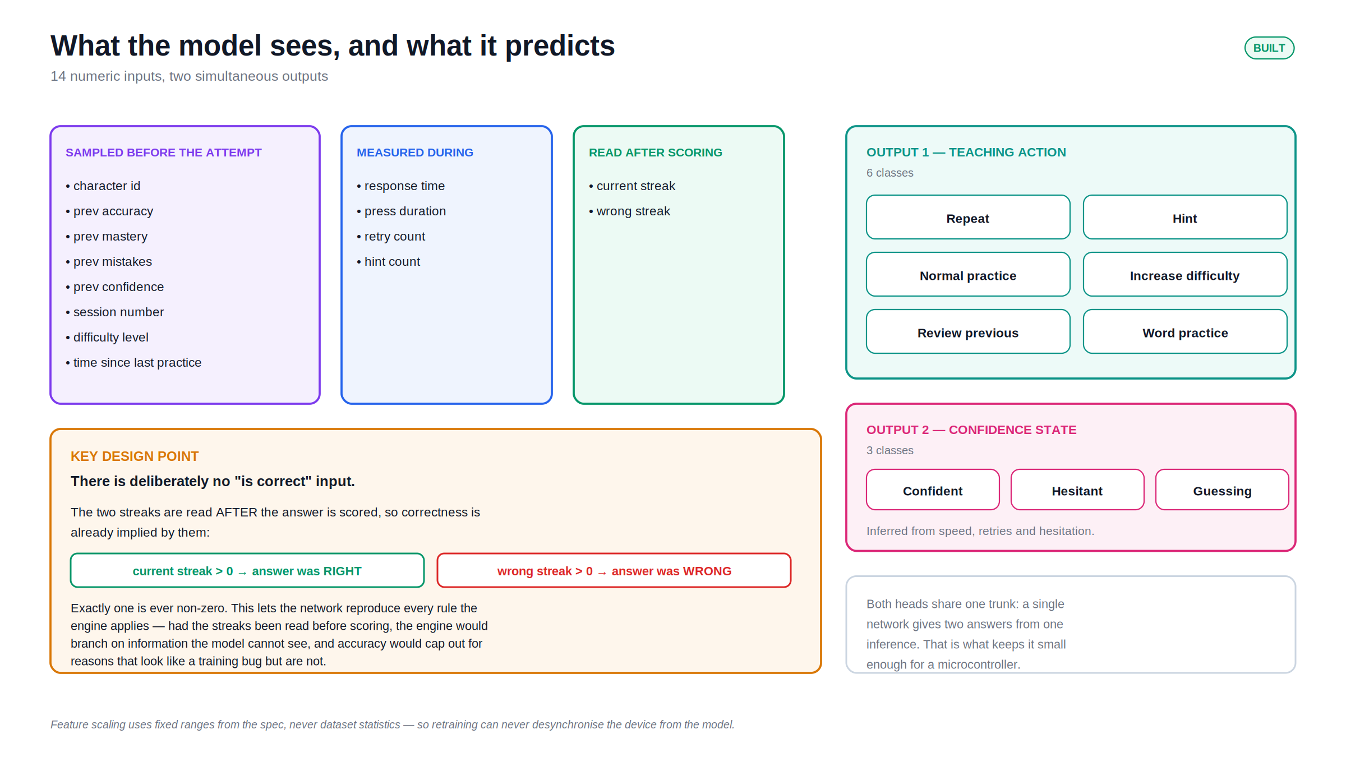
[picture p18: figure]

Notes: The 14 inputs and the 2 outputs. The important design point is on the left: there is no "is correct" input. The two streaks are read after scoring, so correctness is already implied by them. That is what lets the network reproduce every rule the engine applies.

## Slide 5

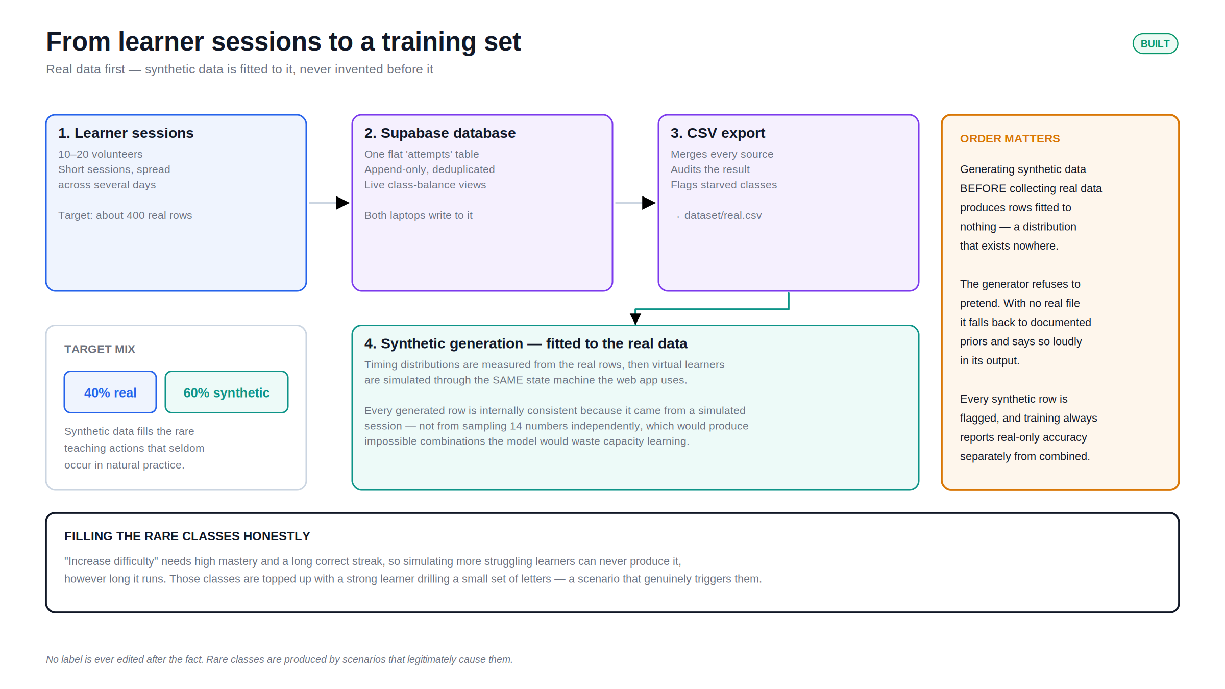
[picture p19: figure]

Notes: How the training set is built. The order is deliberate: collect real data first, measure its timing distributions, then generate synthetic data fitted to those measurements. Generating synthetic data first would produce rows fitted to nothing.

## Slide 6

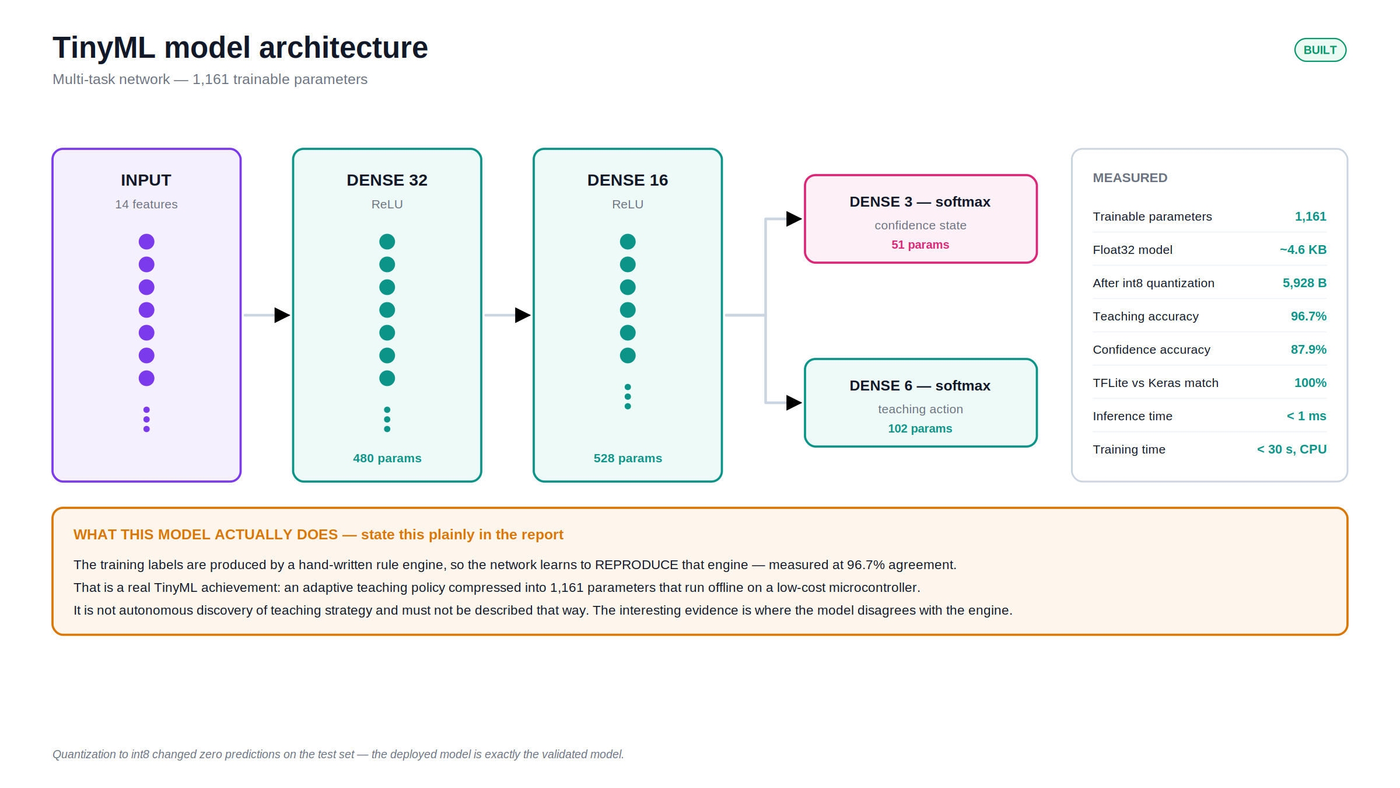
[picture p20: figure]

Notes: The model itself. 1,161 parameters, 5,928 bytes after quantization. The amber band at the bottom is the honest framing: the labels come from a hand-written rule engine, so the network learns to reproduce that engine at 96.7 per cent. That is a real achievement in compression, not autonomous discovery of teaching strategy.

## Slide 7

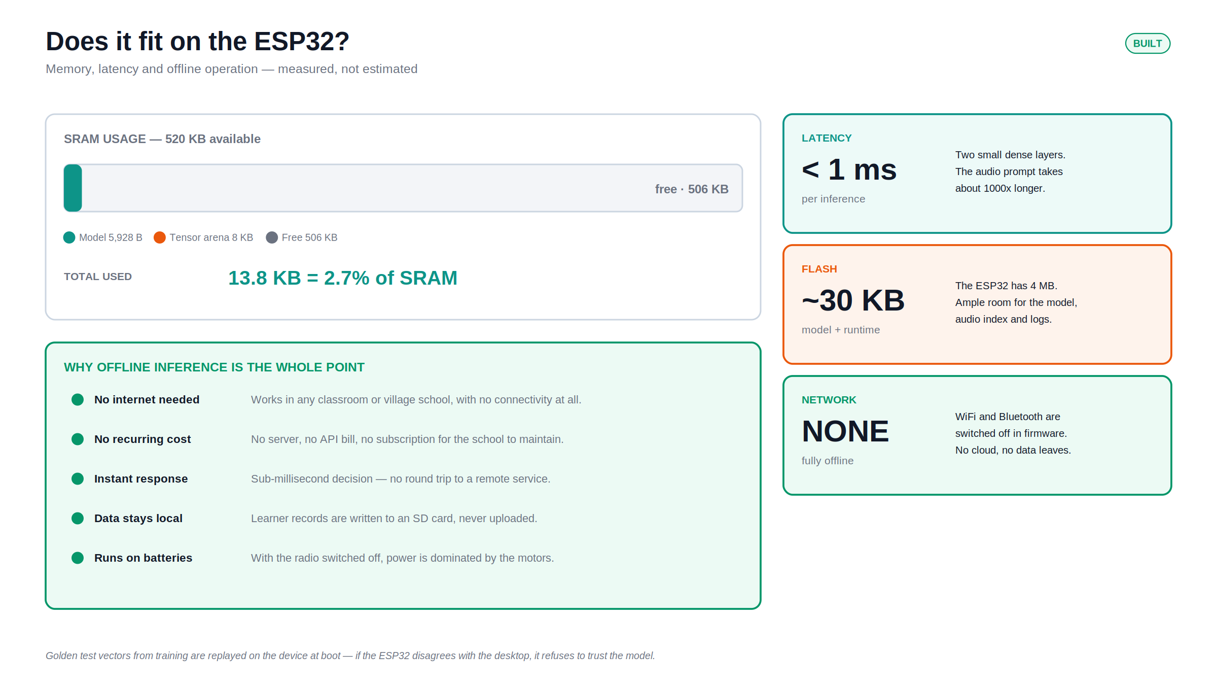
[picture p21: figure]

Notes: Does it fit? Comfortably. 13.8 KB of 520 KB — under three per cent of the memory. Inference is under a millisecond. And it runs with the radio switched off, so the device needs no internet, costs nothing to run, and keeps every learner record local.

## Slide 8

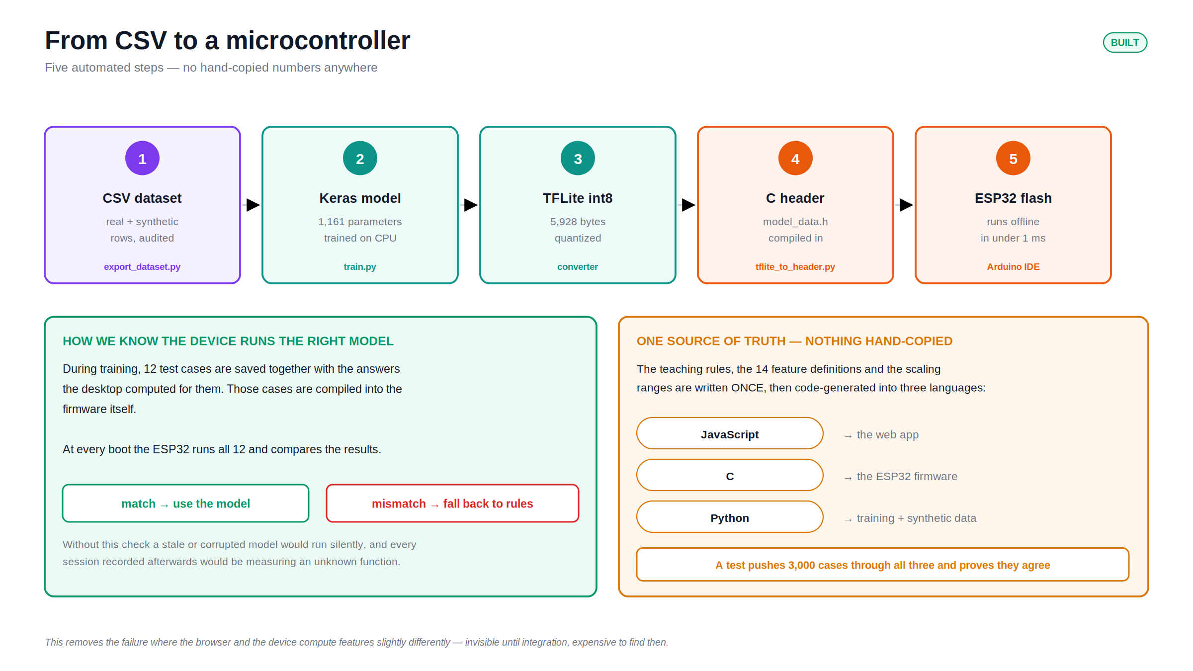
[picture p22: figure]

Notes: Five automated steps from CSV to a flashed microcontroller, with no hand-copied numbers. Two safeguards matter: golden test vectors are replayed on the device at boot, and the rules exist in one place then generate into three languages, proven equal across 3,000 test cases.

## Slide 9

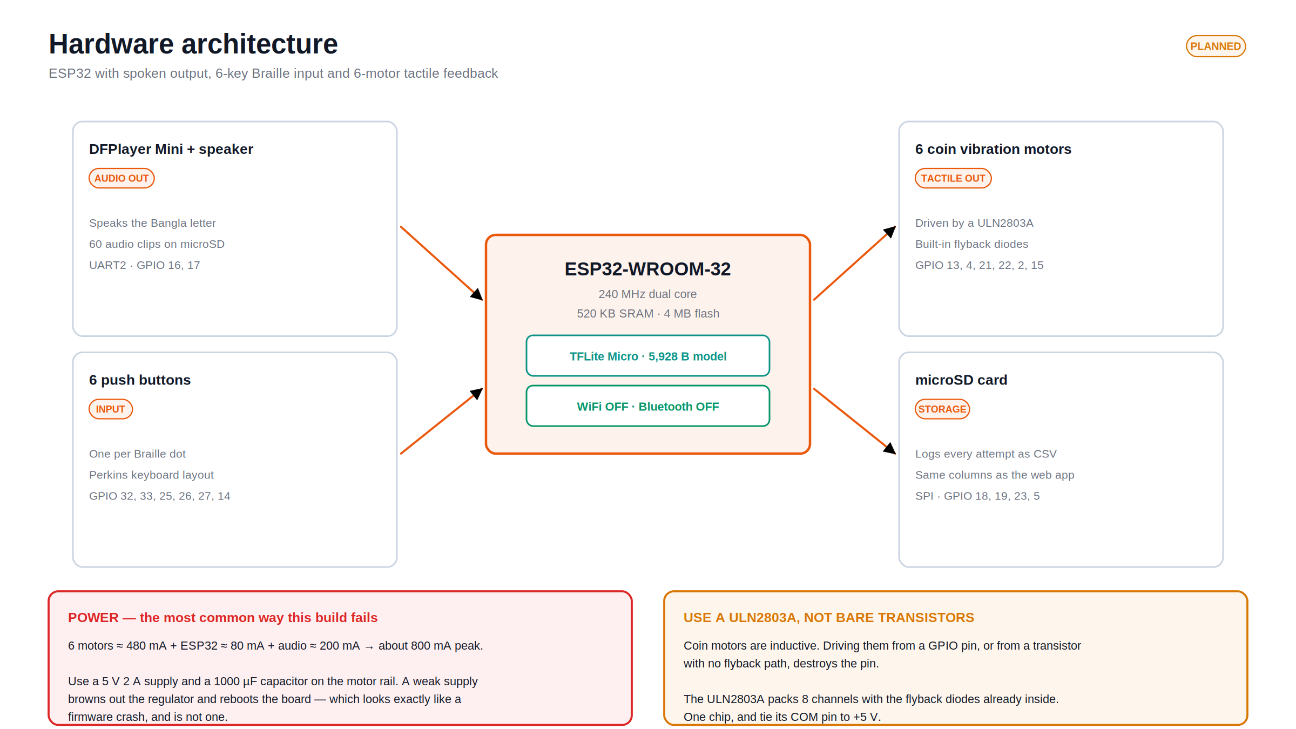
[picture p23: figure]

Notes: The hardware. An ESP32 with a speaker, six buttons, six vibration motors and an SD card. The two red and amber boxes are the failure modes that most often kill a build like this: an under-powered supply that reboots the board mid-session, and driving inductive motors without flyback protection.

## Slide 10

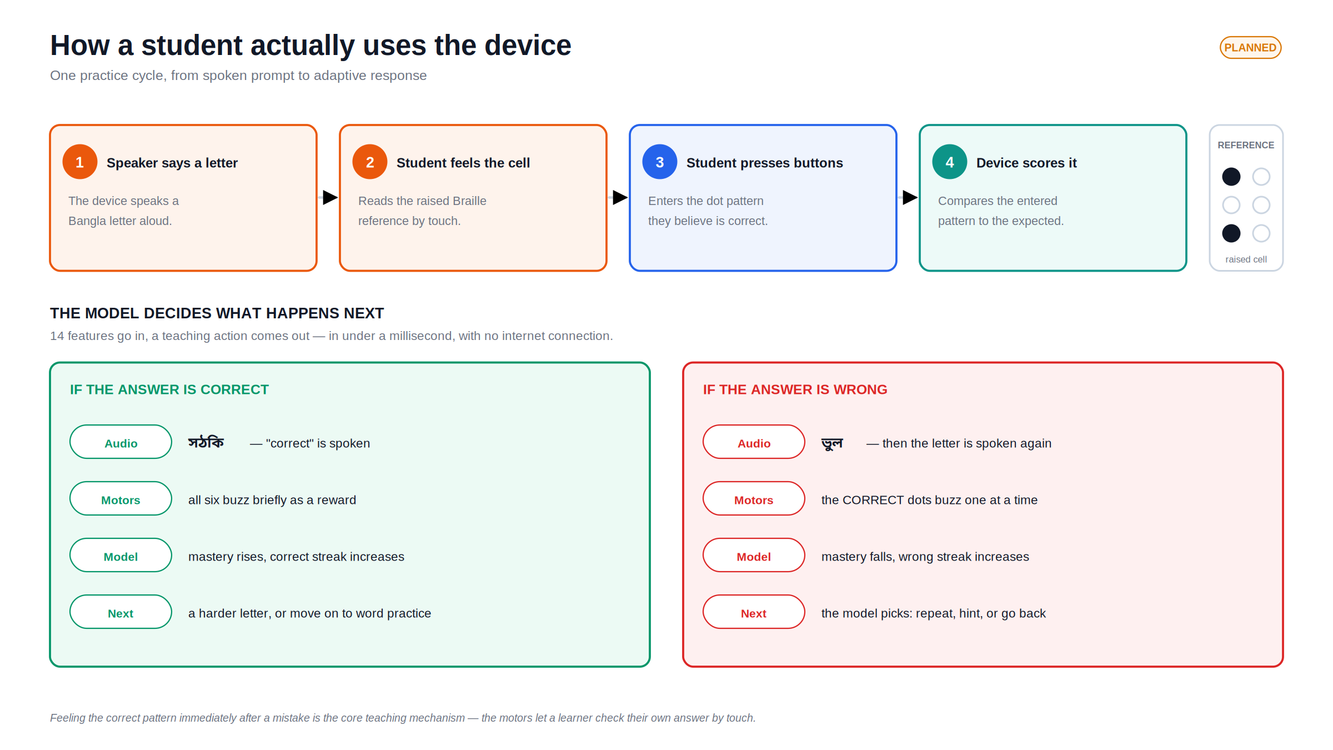
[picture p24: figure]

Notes: What a student actually experiences. The device speaks a letter, they feel the raised reference, they press the dots they believe are right. If wrong, the correct dots buzz one at a time — that is the core teaching mechanism, letting a blind learner check their own answer by touch.

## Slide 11


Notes: The six decisions the system can make, and the exact rule that triggers each one. Note the two steps at the bottom: the rules are written first from teaching principles, and the network is then trained to reproduce them small enough to run on the microcontroller.

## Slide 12


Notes: The planned teacher app. A teacher does not want raw rows — they want to know who is improving, which letters are failing, and what to do next. The data needs no new pipeline: it comes from the SD card or the same database the web app already writes to.

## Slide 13


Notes: Honest status. The software is built and tested. The Braille data is partly verified. Real learner data, the hardware and the app have not been started. The critical path is data collection, because it needs calendar time — learners must practise on different days — and no amount of effort compresses that.

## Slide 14

What this project has NOT yet shown

Stating these plainly is stronger than being asked about them

No real learner data yet

Every accuracy figure comes from a synthetic pipeline test. Those rows were simulated and labelled by the same rule engine the model reproduces, so the numbers are circular.

Only 11 of 50 characters verified

The 11 vowels were read from reference images. The 39 consonants are still placeholder patterns. Of 11 vowel guesses, one was wrong — so roughly 3 or 4 consonants are likely wrong too.

The model imitates a rule engine

It reproduces hand-written rules at 96.7 per cent. That is compression of an explicit policy into 1,161 parameters — a genuine TinyML result, but not autonomous discovery of teaching strategy.

The hardware has never been assembled

The firmware is written and its generated headers compile and self-check, but no physical device exists. Nothing has run on real silicon.

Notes: These four limitations belong in the presentation, not hidden in an appendix. An examiner who finds them missing will assume they were concealed. Stated up front, they show the project is understood rather than oversold. Each one has a clear route to being resolved.

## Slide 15

What happens next

One task is on the critical path. Everything else runs in parallel.

CRITICAL PATH · start today

Collect real learner data

Each learner must practise on DIFFERENT DAYS. Two of the 14 features — session number and time since last practice — carry no signal at all if every session happens in one sitting. This is calendar time, and no amount of effort compresses it.

IN PARALLEL

Supply 39 consonant images

Drop them in, run one command. Fixes the remaining Braille patterns.

Order and assemble hardware

Work through the six bring-up sketches, one peripheral at a time.

Re-record the audio

Replace synthetic speech with a human voice. Same filenames, drop-in.

Retrain on real data

One day of work once the sessions exist. Then reflash the device.

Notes: The single most important point: data collection cannot be rushed at the end. It needs learners practising across multiple days, so it must start immediately and run while the hardware is being built. Everything in the lower half can happen at the same time.

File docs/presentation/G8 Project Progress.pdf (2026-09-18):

## EEE 416 – Microprocessor and Embedded Systems Laboratory

## Jan 2026 Level-4 Term-I Section A2


# Project Proposal

Bangladesh University of Engineering and Technology Department of Electrical and Electronic Engineering

# AI Driven Bangla Braille Learning Device

Santu Nag
2106055

Md. Adib Hasan Audhi
2106056

Mishat Hasan Milon
2106059

Khalid Mehebub
2106065

Submitted by – Group 08


•Build an interactive device for learning

Bangla Braille.

•Let users learn Bangla Braille by using

vibration and audio feedback.

•Let users practice Braille using push


buttons.

•Use AI to adapt learning based on user

performance.

•Keep the system low-cost and user

friendly.

Presented by: 2106055

# 3.Literature Review

## Hardware-Based Braille Learning Systems

Paper | Main Work | Research Gap for Our Project
Kader et al. (2018) Developing A Self-Learning Braille Kit for Visually Impaired People | Built a self learning Bengali Braille kit using six actuators and audio. It supports learning mode and practice mode. | Costly and it does not include ML/AI based implementation.
Saikot & Sanim (2022) Refreshable Braille Display With Adjustable Cell Size for Learners With Different Tactile Sensitivity | Developed a singlecell refreshable Braille display with six electromechanical actuators, adjustable dot spacing, and speech support. | Expensive.It does not have practice mode.It doesn’t include ML/AI based implementation as well.
Ma, Lai & Luo (2025) BrailleRhythm: Enhancing Braille Character Recognition and Learning via Real-time Tactile Sensing and Audio Feedback | Placed a pressure-sensor sheet over Braille cards. The system detects touched Braille patterns and gives real-time audio feedback. | It is not Bangla focused and does not test learner answers, retries, or adaptive teaching actions.

# 4.Methodology


ESP32 Dev Kit
(MCU)

DFPlayer Mini
(Audio Feedback)

Tactile Push Buttons
(User Braille Input)

1030 Coin Vibration Motor
(Haptic Feedback)


Haptic Teaching Module:
This module teaches Bangla Braille using both audio and vibration, so the learner can hear the letter and feel its Braille pattern.

Auditory Pathway:
The ESP32 selects a letter and sends a command to the DFPlayer, which plays the corresponding Bangla audio through the speaker.

Haptic Pathway:
At the same time, the ESP32 controls the motor driver to activate the required combination of six vibration motors, creating the Braille pattern as haptic feedback.


Real-Time Input & Assessment

i. Tactile Input Pathway:
The learner enters a Braille character using the 6 dot button matrix. The ESP32 reads the input and records features.

ii. Data Processing & Logging:
The ESP32 processes the 6-bit Braille pattern and stores the attempt result and collected features in a CSV file through the microSD module for further evaluation.

# 5 Progress

01.

Characters; output

Braille Input Interface

Push Button combinations read by
the ESP32 to identify Bangla Braiile

Braille to Speech Conversion

Detected Braille letters are converted into

corresponding Bangla output

Haptic Braille Display

Six 1030 vibration motors
providing Haptic feedback

Serial Input to Haptic and Speech Output

Serial input triggers the corresponding
Braille vibration pattern and speech

# 5 Progress


1030 Coin Vibration Motor
(Haptic Feedback)

Push Button Braille Display with Speaker

# 5 Progress


Web Platform for Practice and ML Data Collection

## 1.Letter Sound: The speaker plays the sound of a target

letter.

## 2.User Response: The user listens to the sound and presses

the corresponding push button.

## 3.System Evaluation: The system checks the selected button

against the correct letter.

## 4.Feedback: The result is provided through vibration and/or

speaker feedback.

## 5.Learning Update: The response is recorded for future

learning and performance analysis.

# Remaining Task –1 : Testing Phase

# Remaining Task –2 : Model Architecture


Previous proposed Inputs (14)

char_id
response_time
press_duration
retry_count
prev_accuracy
prev_mastery
hint_count
session_number
difficulty_level
time_since_last_practice
prev_confidence
current_streak
wrong_streak
prev_mistakes

Updated Inputs (8)

response_time
press_duration
retry_count
prev_accuracy
prev_mastery
hint_count
current_streak
wrong_streak

# Remaining Task –2 : Model Architecture

Previously proposed Output (teaching_action)

REPEAT
HINT
NORMAL_PRACTICE
INCREASE_DIFFICULTY
REVIEW_PREVIOUS

WORD_PRACTICE

Updated Output
(teaching_action)

REPEAT

HINT

NORMAL_PRACTICE

REVIEW_PREVIOUS

# Remaining Task –2 : Model Architecture


[N.B.: This is an AI-generated concept design for visualization purposes only]

# Remaining Task –3 : 3d model design

EEE 416 (2022) – Final Project | Presented by: 2106059

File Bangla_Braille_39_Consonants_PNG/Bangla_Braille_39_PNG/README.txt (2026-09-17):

Bangladesh Bangla Braille — 39 Bengali consonants

This package contains exactly 39 PNG files, one for each letter/sign in the
commonly taught 39-consonant Bengali alphabet. The last three (ং, ঃ, ঁ) are
classified as special/modifier characters in Braille references but are
traditionally counted in the 39-letter Bengali consonant set.

The conjuncts ক্ষ and জ্ঞ are not part of this 39-item package.

Mapping:
01. ক  ⠅  dots 13
02. খ  ⠭  dots 1346
03. গ  ⠛  dots 1245
04. ঘ  ⠣  dots 126
05. ঙ  ⠬  dots 346
06. চ  ⠉  dots 14
07. ছ  ⠡  dots 16
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

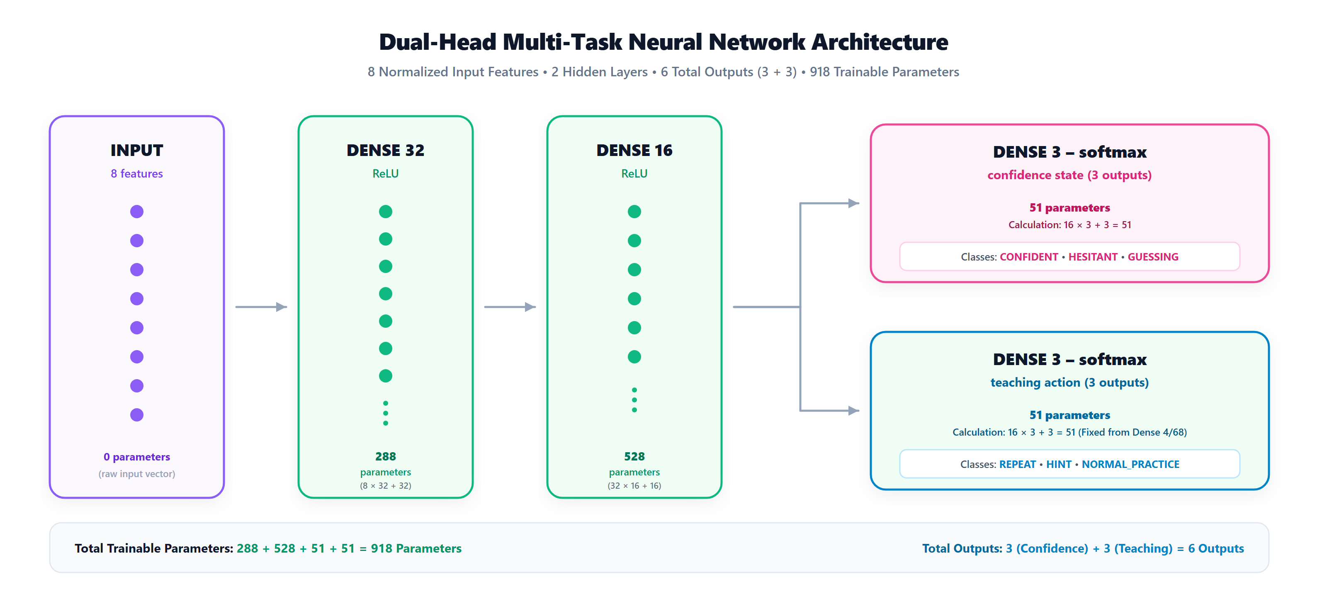
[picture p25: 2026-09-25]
presentation_assets/fixed_model_architecture.png

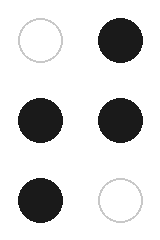
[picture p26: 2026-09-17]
assets/braille/46_khanda_ta.png

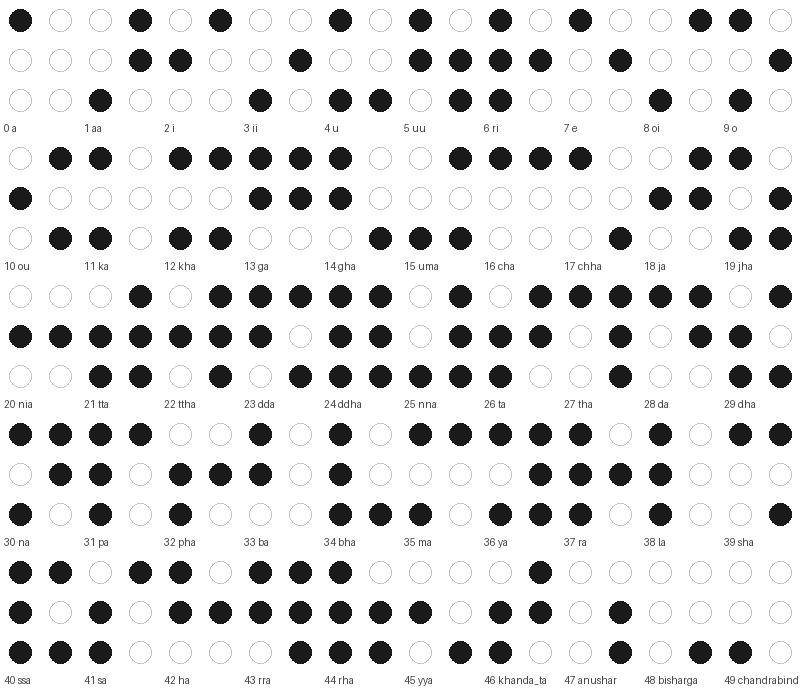
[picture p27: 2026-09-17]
assets/braille/_contact_sheet.png

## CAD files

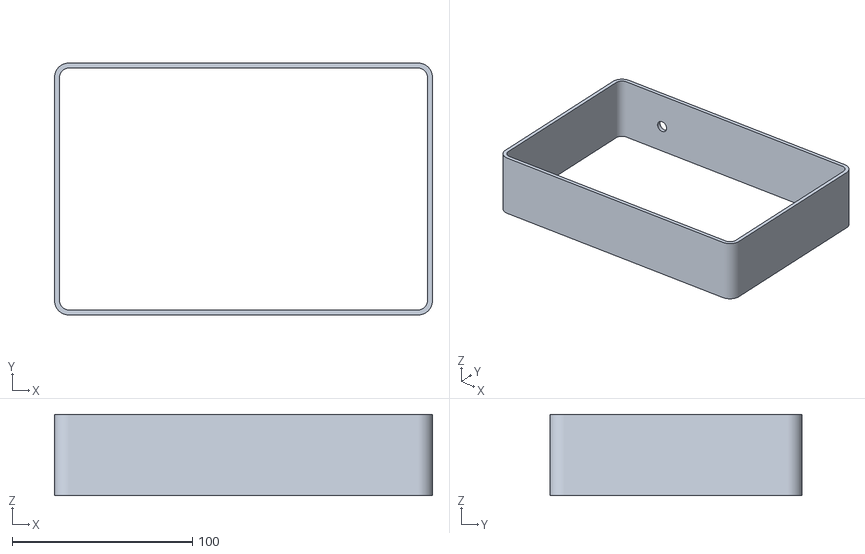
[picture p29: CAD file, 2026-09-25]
enclosure/case_walls.stl
210.0 x 140.0 x 45.2

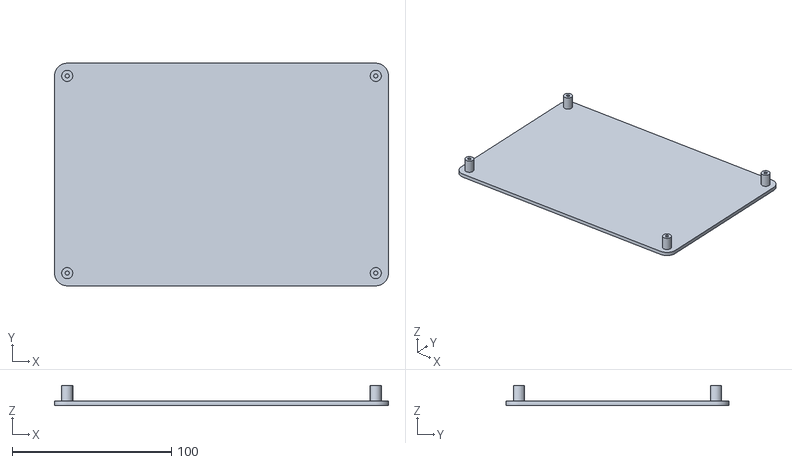
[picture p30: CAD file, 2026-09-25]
enclosure/case_base.stl
210.0 x 140.0 x 12.8

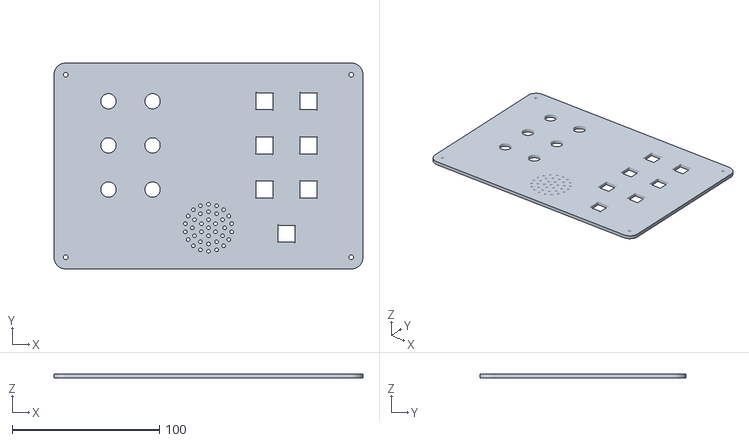
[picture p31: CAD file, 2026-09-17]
enclosure/top_panel.stl
210.0 x 140.0 x 2.80

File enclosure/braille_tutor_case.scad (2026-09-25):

// ====================================================================
// AI-Assisted Bangla Braille Tutor - top lid, parametric
//
// SUPERSEDED: this file builds the top panel and its 48 mm skirt as one
// merged solid. That duplicates top_panel.stl, which gets printed and
// used on its own. The current three-piece enclosure is:
//   1. top_panel.stl   -- the flat top panel (printed separately)
//   2. case_walls.scad -- an open-top/open-bottom frame the panel rests on
//   3. case_base.scad  -- the flat cover underneath
// Use case_walls.scad + case_base.scad for a new build; this file is kept
// for reference (and for anyone who wants a single all-printed top half
// instead of a separate panel).
//
// This is the TOP half only: a rounded shell with a downward skirt and
// every component hole in its top face. Nothing decorative -- no text,
// no engraved zones, no dividers. Just the shell and the cutouts.
//
// The hole layout is NOT defined here. It comes from
// top_panel_layout.scad, which tools/gen_top_panel.py generates from the
// same numbers as top_panel_cutout.svg. That way the printed lid and the
// laser-cut panel are the same part by construction. To move a hole,
// edit tools/gen_top_panel.py and re-run it.
//
// Compatible with OpenSCAD / FreeCAD.
// ====================================================================

include <top_panel_layout.scad>

$fn = 72;   // smooth circles

// --- Shell ----------------------------------------------------------
case_width     = PANEL_W;    // 210
case_depth     = PANEL_H;    // 140
case_height    = 48.0;       // clearance for ESP32, ULN2803A, DFPlayer, wiring
wall_thickness = 2.8;
top_thickness  = PANEL_T;    // 2.8
corner_radius  = CORNER_R;   // 8

// Cutting plane for the top face: start below it and run past it, so every
// hole is an unambiguous through cut with no coincident-face artefacts.
cut_z = case_height - top_thickness - 1;
cut_h = top_thickness + 2;


// --- Modules --------------------------------------------------------

module rounded_box(w, d, h, r) {
    hull() {
        translate([r, r, 0])     cylinder(r = r, h = h);
        translate([w - r, r, 0]) cylinder(r = r, h = h);
        translate([r, d - r, 0]) cylinder(r = r, h = h);
        translate([w - r, d - r, 0]) cylinder(r = r, h = h);
    }
}

// A square hole with relieved corners, matching the SVG's rx/ry.
module rounded_square_hole(size, r, h) {
    hull() {
        for (dx = [-1, 1], dy = [-1, 1])
            translate([dx * (size / 2 - r), dy * (size / 2 - r), 0])
                cylinder(r = r, h = h);
    }
}

// 6 coin vibration motors, dia 10 x 3 mm.
// Through holes, not pockets: the motor is bonded in with its face flush to
// the panel top so the fingertip touches the motor itself.
module motor_cutouts() {
    for (p = MOTOR_POS)
        translate([p[0], p[1], cut_z])
            cylinder(d = MOTOR_HOLE_DIA, h = cut_h);
}

// 6 dot buttons + 1 submit, 12 x 12 x 6 mm 4-pin tactile switches.
// Square cutouts: the switch body presses up through the panel, which then
// captures it just below the cap.
module button_cutouts() {
    for (p = BTN_POS)
        translate([p[0], p[1], cut_z])
            rounded_square_hole(BTN_HOLE, BTN_HOLE_R, cut_h);
}

// Acoustic grill for the dia 40 mm speaker. The perforated area spans the
// cone only, so the speaker frame lands on solid material.
module speaker_grill() {
    for (p = GRILL_POS)
        translate([p[0], p[1], cut_z])
            cylinder(d = GRILL_HOLE_DIA, h = cut_h);
}

// M3 clearance holes. The mating standoffs belong to the base half, which
// this file does not model. Use pan-head or washered screws: at 2.8 mm the
// top face is too thin to countersink an M3 head without breaking through.
module screw_cutouts() {
    for (p = SCREW_POS)
        translate([p[0], p[1], cut_z])
            cylinder(d = SCREW_DIA, h = cut_h);
}

// Wire pass-through: a round hole through the back wall, offset to one
// side rather than centred, for the power/USB cable to leave the case.
wire_hole_dia = 8.0;
wire_hole_x   = 40;   // off to one side of the back wall, not its centre (105)
wire_hole_z   = 20;   // within the wall's solid height, clear of the top cap

module wire_pass_hole() {
    translate([wire_hole_x, case_depth - wall_thickness - 1, wire_hole_z])
        rotate([-90, 0, 0])
            cylinder(d = wire_hole_dia, h = wall_thickness + 2, $fn = 48);
}


// --- Assembly -------------------------------------------------------

module top_lid() {
    difference() {
        rounded_box(case_width, case_depth, case_height, corner_radius);

        // hollow out everything below the top face
        translate([wall_thickness, wall_thickness, -1])
            rounded_box(
                case_width  - 2 * wall_thickness,
                case_depth  - 2 * wall_thickness,
                case_height - top_thickness + 1,
                corner_radius - 1
            );

        motor_cutouts();
        button_cutouts();
        speaker_grill();
        screw_cutouts();
        wire_pass_hole();
    }
}

top_lid();

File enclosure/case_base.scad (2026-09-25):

// ====================================================================
// AI-Assisted Bangla Braille Tutor - bottom base, parametric
//
// This is the BASE half that closes underneath braille_tutor_case.scad's
// top lid. It shares PANEL_W, PANEL_H and CORNER_R with the top panel
// (via top_panel_layout.scad), so the footprint and corner radius always
// line up exactly with the lid -- nothing here is measured independently.
//
// The brief is a total assembled height of 2 in (50.8 mm) measured from
// the ground to the top panel. The lid alone (braille_tutor_case.scad) is
// already 48 mm, so this base is a flat cover, not a second deep shell:
// base_thickness = 50.8 - 48 = 2.8 mm, the same thickness as the top
// panel itself. That is what keeps the assembly a single 50.8 mm box
// instead of stacking two full-height shells into a doubled-up one.
//
// Screw bosses rise from this cover, up into the lid's hollow interior,
// under the top lid's SCREW_POS -- the same four M3 screws that pass
// through the lid's clearance holes thread into these bosses. The wire
// pass-through hole lives in the top lid's back wall instead (see
// braille_tutor_case.scad), not here, so this cover stays a plain panel.
//
// Compatible with OpenSCAD / FreeCAD.
// ====================================================================

include <top_panel_layout.scad>

$fn = 72;   // smooth circles

// --- Cover --------------------------------------------------------------
base_width     = PANEL_W;     // 210, identical to the top lid
base_depth     = PANEL_H;     // 140, identical to the top lid
base_thickness = PANEL_T;     // 2.8 mm: 50.8 mm assembled - 48 mm lid = 2.8 mm cover
corner_radius  = CORNER_R;    // 8, identical to the top lid -> corners always align

// M3 screw bosses, centred on the same four points as the top lid's
// screw_cutouts(). They rise into the lid's ~45 mm clear interior, so
// only need enough length for a secure screw grip, not the full height.
boss_od        = 7.0;
boss_pilot_dia = 2.6;   // self-tapping pilot for an M3 screw in PLA/PETG
boss_height    = 10.0;


// --- Modules ------------------------------------------------------------

module rounded_box(w, d, h, r) {
    hull() {
        translate([r, r, 0])         cylinder(r = r, h = h);
        translate([w - r, r, 0])     cylinder(r = r, h = h);
        translate([r, d - r, 0])     cylinder(r = r, h = h);
        translate([w - r, d - r, 0]) cylinder(r = r, h = h);
    }
}

module base_cover() {
    rounded_box(base_width, base_depth, base_thickness, corner_radius);

    // Screw bosses, aligned to the top lid's SCREW_POS so a single M3
    // screw clamps through both halves.
    for (p = SCREW_POS)
        translate([p[0], p[1], base_thickness])
            difference() {
                cylinder(d = boss_od, h = boss_height);
                cylinder(d = boss_pilot_dia, h = boss_height + 1);
            }
}

base_cover();

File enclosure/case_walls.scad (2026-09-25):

// ====================================================================
// AI-Assisted Bangla Braille Tutor - side walls, parametric
//
// This is the middle part of a THREE-piece enclosure:
//
//   1. top_panel.stl        -- the flat top panel (already printed).
//   2. case_walls.scad      -- THIS FILE: an open-top, open-bottom frame
//                               that the top panel rests on.
//   3. case_base.scad       -- a flat cover that closes the bottom.
//
// It shares PANEL_W, PANEL_H and CORNER_R with the top panel (via
// top_panel_layout.scad), so its footprint and corner radius match the
// already-printed panel exactly -- the panel sits flush on this frame's
// top rim, no separate measuring needed.
//
// It carries no top face and none of the panel's cutouts (motor, button,
// speaker, screw) -- those already exist on the printed panel. It is
// just a hollow tube, plus the wire pass-through hole.
//
// Height: the brief is a total assembled height of 2 in (50.8 mm), ground
// to top panel. The top panel (2.8 mm) sits on top of these walls, and
// the base cover (2.8 mm) sits underneath, so:
//     wall_height = 50.8 - 2.8 (panel) - 2.8 (base) = 45.2 mm
//
// The four M3 screws drop straight down through the panel's SCREW_POS,
// through this frame's open interior (the screw positions sit inboard of
// the wall thickness, so nothing here needs its own screw holes), into
// the bosses on case_base.scad.
//
// Compatible with OpenSCAD / FreeCAD.
// ====================================================================

include <top_panel_layout.scad>

$fn = 72;   // smooth circles

// --- Frame ----------------------------------------------------------
wall_width     = PANEL_W;    // 210, identical to the top panel
wall_depth     = PANEL_H;    // 140, identical to the top panel
wall_height    = 45.2;       // 50.8 total - 2.8 top panel - 2.8 base cover
wall_thickness = 2.8;        // matches the top panel's thickness
corner_radius  = CORNER_R;   // 8, identical to the top panel -> edges always align

// Wire pass-through: a round hole through the back wall, offset to one
// side rather than centred, for the power/USB cable to leave the case.
wire_hole_dia = 8.0;
wire_hole_x   = 40;   // off to one side of the back wall, not its centre (105)
wire_hole_z   = 20;   // within the wall's height, clear of both rims


// --- Modules ----------------------------------------------------------

module rounded_box(w, d, h, r) {
    hull() {
        translate([r, r, 0])         cylinder(r = r, h = h);
        translate([w - r, r, 0])     cylinder(r = r, h = h);
        translate([r, d - r, 0])     cylinder(r = r, h = h);
        translate([w - r, d - r, 0]) cylinder(r = r, h = h);
    }
}

module wire_pass_hole() {
    translate([wire_hole_x, wall_depth - wall_thickness - 1, wire_hole_z])
        rotate([-90, 0, 0])
            cylinder(d = wire_hole_dia, h = wall_thickness + 2, $fn = 48);
}

module side_walls() {
    difference() {
        rounded_box(wall_width, wall_depth, wall_height, corner_radius);

        // hollow out the interior -- open top, open bottom
        translate([wall_thickness, wall_thickness, -1])
            rounded_box(
                wall_width  - 2 * wall_thickness,
                wall_depth  - 2 * wall_thickness,
                wall_height + 2,
                corner_radius - wall_thickness
            );

        wire_pass_hole();
    }
}

side_walls();

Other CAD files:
enclosure/top_panel_layout.scad

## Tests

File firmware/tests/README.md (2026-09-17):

# Bring-up sketches — run these in order

Do **not** flash `braille_tutor.ino` first. It drives six buttons, six motors,
a DFPlayer, an SD card and a neural network at once; if anything is miswired
you get one symptom and eighteen possible causes.

Each sketch here adds exactly one peripheral. Every one prints what it expects
to see, so you know whether it passed without guessing.

| # | Sketch | Proves | Typical failure |
|---|---|---|---|
| 1 | `t1_blink_serial` | Board alive, serial at 115200 | Wrong board selected, bad USB cable (many are charge-only) |
| 2 | `t2_buttons` | All 6 buttons, debounce, press timing | Button on a pin with no internal pull-up |
| 3 | `t3_motors` | ULN2803A drives each motor | COM pin not tied to +5V — motors weak or GPIO dies |
| 3b | `t3b_braille_patterns` | A typed letter buzzes the right dots | Motor channel swapped — dot 3 fires where dot 4 should |
| 4 | `t4_dfplayer` | Audio plays by track number | Files not in `/mp3`, or not named `0001.mp3` |
| 5 | `t5_sd` | Card mounts, CSV appends | 3.3V-only module fed 5V, or CS on the wrong pin |
| 6 | `t6_model` | *(legacy TFLite test — superseded)* The main firmware now uses `model_weights.h` + `inference.h` (pure C float arrays, no arena). Skip this unless you are specifically debugging a TFLite build. | Arena too small, or stale `model_data.h` |

Only after all six pass should you flash `braille_tutor.ino`. `t3b` is optional
for bring-up but is the one place you can check a Braille cell by touch before
the whole tutor is running: type a letter number (1–50) or its name into the
Serial Monitor and the motors buzz its dots in reading order — 1 2 3 down the
left column, then 4 5 6 down the right. It prints the cell as ASCII at the same
time, so you can see what you should be feeling.

## Power, before you start

Six motors at once pull ~480 mA. Add the ESP32 and DFPlayer and you are near
800 mA peak. Use a **5 V 2 A supply**, not a laptop USB port, and put a
**1000 µF capacitor across the motor rail**. Without it the motor inrush
browns out the 3V3 regulator and the ESP32 reboots mid-session — which looks
exactly like a firmware crash and is not one. If your board resets whenever
several motors fire together, this is why.

Never drive motors from the ESP32's 3V3 pin. Common ground everywhere.

## Generating the headers

Sketches 3b and 6 and the main firmware need the generated headers, and each
Arduino sketch folder needs its own copy. From the repo root:

```bash
python3 tools/gen_engine.py          # regenerates rule_engine.h, rule_engine.js, rule_engine_gen.py
python3 tools/gen_braille_header.py  # regenerates braille_map.h
python3 tools/train_and_export.py    # trains sklearn MLP, exports model_weights.h + golden_vectors.json
cp firmware/braille_tutor/braille_map.h firmware/tests/t3b_braille_patterns/
# t6_model uses model_data.h (TFLite, legacy) -- skip if using the current sklearn pipeline
```

Re-run the copy after every `gen_braille_header.py` — the copies are snapshots,
and a stale one means `t3b` buzzes a pattern the rest of the system no longer
believes in.

## Model deployment — current pipeline (sklearn → C arrays)

The project no longer uses TFLite. The model is exported directly as C float
arrays by `tools/train_and_export.py`:

```
firmware/braille_tutor/model_weights.h   1,734 floats (6,936 bytes), PROGMEM-ready
firmware/braille_tutor/inference.h       forward pass: ml_infer(&features, &ta, &cs)
firmware/braille_tutor/rule_engine.h     normalize_features() + Features struct
```

No arena, no quantization, no runtime library. Call `ml_infer()` anywhere
`rule_engine.h` is included. Inference time: ~0.1 ms at 240 MHz.

To verify the exported model matches training, use the 20 golden vectors in
`models/golden_vectors.json` — each has `features_raw`, `features_norm`,
`expect_teaching`, and `expect_confidence`. `t11_ml_test` runs these vectors
against the live hardware and prints PASS/FAIL to Serial Monitor at boot.

---

## Remote / cloud-connected sketches — a separate track

Everything above builds toward `braille_tutor.ino`, which is deliberately
WiFi-free. The sketches below are a **parallel, separate mode**: the ESP32
joins WiFi and polls Supabase for commands from `web/teacher.html`, instead of
running the on-device model. See the root `README.md`'s "Remote / cloud-
connected mode" section for the full data-flow diagram and one-time Supabase
setup. Summary here:

| Sketch | Role | Flash it when... |
|---|---|---|
| `t7_cloud_dot` | Earliest bring-up: buzz one dot on command | Verifying WiFi + Supabase reachability, motors only |
| `t8_cloud_quiz` | Full quiz flow prototype | Superseded by `t11_testing`; kept for reference |
| `t9_dfplayer_test` | Pure DFPlayer diagnostic, no WiFi | Audio not playing and you need to isolate hardware from network |
| `t10_learning` | Teach mode: audio + vibration, retries until correct, reports every attempt to `attempts` | Teacher panel's শেখানো (Learn) tab |
| `t11_testing` | Assessment mode: audio only, one attempt, no retry, Serial batch summary at the end | Teacher panel's পরীক্ষা (Test) tab |
| `firmware/t11_ml_test/` *(one level up, not under `tests/`)* | Same as `t10_learning` but also runs the on-device ML model and logs its real decision, for inspecting model-vs-rule-engine agreement | Comparing the trained model against the rule engine on real presses |

Only flash **one of these at a time** — they share `device_id: "esp32_01"`
and will all respond to the same `remote_commands` rows otherwise, which
looks like the board answering with the wrong behavior. Each folder has its
own `secrets.h` (gitignored) that needs real `WIFI_SSID`/`WIFI_PASS` filled
in before it'll connect.

**Verified pin mapping** (all remote-mode sketches share this — see each
folder's `pins.h`):

```
PIN_BUTTON = { 32, 33, 25, 26, 27, 14 }   // dot 1..6
PIN_MOTOR  = { 21, 13, 22, 2, 15, 4 }     // dot 1..6 -- confirmed against
                                          // physical wiring via a button-
                                          // press-buzzes-same-dot sync test;
                                          // do not "simplify" this ordering
PIN_SUBMIT = 12                          // strapping pin, must read LOW at boot
```

If you rewire and need to re-verify this mapping, flash `t_sync_test`: hold
each dot button in turn and confirm the SAME dot's motor buzzes. `t_motor_test`
is the same idea without WiFi, for isolating a motor/ULN2803A problem from the
network stack.

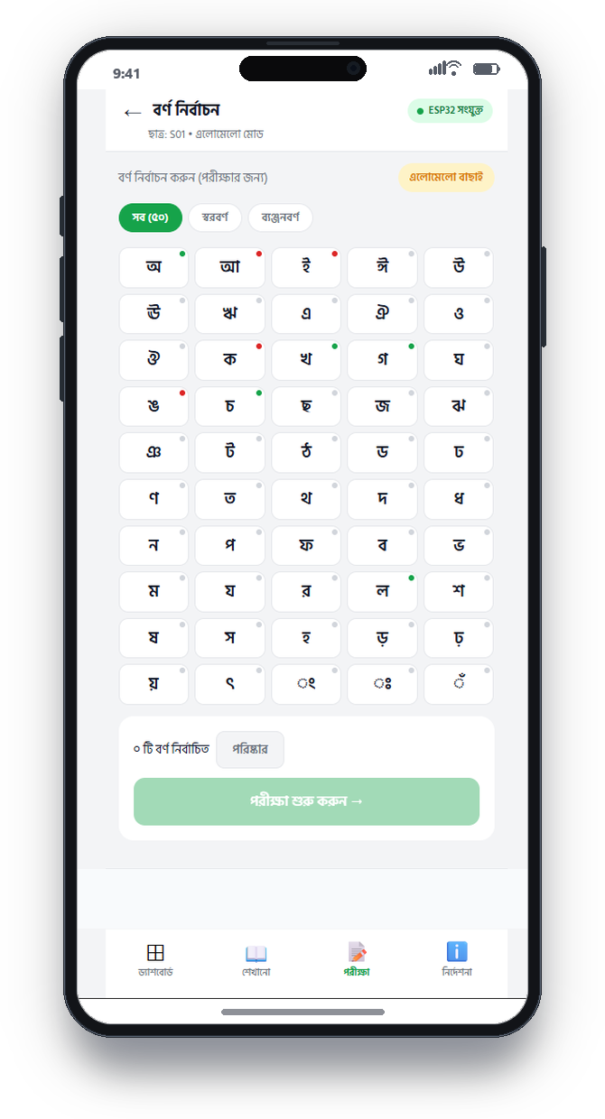
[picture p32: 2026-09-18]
presentation_assets/mockup_3_testing_evaluation.png

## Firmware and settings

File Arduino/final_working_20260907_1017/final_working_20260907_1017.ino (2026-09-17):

// ============================================================
//  p6 — TRIPLE MODE: menu, learn, test
//  FIXED: BRAILLE_PATTERN corrected from Bangladesh chart
// ============================================================

#include <Arduino.h>
#include <DFRobotDFPlayerMini.h>

const int buttonPins[6]   = {4, 5, 15, 19, 21, 22};
const int submitButtonPin  = 18;
const int enterButtonPin   = 34;
const int PIN_MOTOR[6]    = {13, 14, 26, 27, 32, 33};

#define PIN_DF_ESP_RX 25
#define PIN_DF_ESP_TX 23

HardwareSerial mySoftwareSerial(2);
DFRobotDFPlayerMini dfPlayer;

// ============================================================
//  CORRECTED BANGLADESH BRAILLE PATTERNS
//  Dot layout: 1=top-left 4=top-right
//              2=mid-left 5=mid-right
//              3=bot-left 6=bot-right
//  Bits: Dot1=bit0, Dot2=bit1, Dot3=bit2,
//        Dot4=bit3, Dot5=bit4, Dot6=bit5
// ============================================================
const uint8_t BRAILLE_PATTERN[50] = {
  0x01,  // [ 1] অ   Dot1
  0x03,  // [ 2] আ   Dot1 Dot2
  0x09,  // [ 3] ই   Dot1 Dot4
  0x19,  // [ 4] ঈ   Dot1 Dot4 Dot5
  0x11,  // [ 5] উ   Dot1 Dot5
  0x13,  // [ 6] ঊ   Dot1 Dot2 Dot5
  0x1B,  // [ 7] ঋ   Dot1 Dot2 Dot4 Dot5  (2-cell: prefix Dot6 cell first)
  0x31,  // [ 8] এ   Dot1 Dot5 Dot6
  0x39,  // [ 9] ঐ   Dot1 Dot4 Dot5 Dot6
  0x3B,  // [10] ও   Dot1 Dot2 Dot4 Dot5 Dot6
  0x3A,  // [11] ঔ   Dot2 Dot4 Dot5 Dot6
  0x05,  // [12] ক   Dot1 Dot3
  0x07,  // [13] খ   Dot1 Dot2 Dot3
  0x1B,  // [14] গ   Dot1 Dot2 Dot4 Dot5
  0x0B,  // [15] ঘ   Dot1 Dot2 Dot4
  0x19,  // [16] ঙ   Dot1 Dot4 Dot5
  0x09,  // [17] চ   Dot1 Dot4
  0x29,  // [18] ছ   Dot1 Dot4 Dot6
  0x1A,  // [19] জ   Dot2 Dot4 Dot5
  0x2A,  // [20] ঝ   Dot2 Dot4 Dot6
  0x39,  // [21] ঞ   Dot1 Dot4 Dot5 Dot6
  0x3E,  // [22] ট   Dot2 Dot3 Dot4 Dot5 Dot6
  0x2E,  // [23] ঠ   Dot2 Dot3 Dot4 Dot6
  0x39,  // [24] ড   Dot1 Dot4 Dot5 Dot6
  0x3B,  // [25] ঢ   Dot1 Dot2 Dot4 Dot5 Dot6
  0x1D,  // [26] ণ   Dot1 Dot3 Dot4 Dot5
  0x1E,  // [27] ত   Dot2 Dot3 Dot4 Dot5
  0x36,  // [28] থ   Dot2 Dot3 Dot5 Dot6
  0x19,  // [29] দ   Dot1 Dot4 Dot5
  0x3A,  // [30] ধ   Dot2 Dot4 Dot5 Dot6
  0x1D,  // [31] ন   Dot1 Dot3 Dot4 Dot5
  0x0F,  // [32] প   Dot1 Dot2 Dot3 Dot4
  0x3F,  // [33] ফ   Dot1 Dot2 Dot3 Dot4 Dot5 Dot6
  0x07,  // [34] ব   Dot1 Dot2 Dot3
  0x27,  // [35] ভ   Dot1 Dot2 Dot3 Dot6
  0x0D,  // [36] ম   Dot1 Dot3 Dot4
  0x3D,  // [37] য   Dot1 Dot3 Dot4 Dot5 Dot6
  0x17,  // [38] র   Dot1 Dot2 Dot3 Dot5
  0x1F,  // [39] ল   Dot1 Dot2 Dot3 Dot4 Dot5
  0x29,  // [40] শ   Dot1 Dot4 Dot6
  0x3F,  // [41] ষ   Dot1 Dot2 Dot3 Dot4 Dot5 Dot6
  0x0E,  // [42] স   Dot2 Dot3 Dot4
  0x33,  // [43] হ   Dot1 Dot2 Dot5 Dot6
  0x3B,  // [44] ড়  Dot1 Dot2 Dot4 Dot5 Dot6
  0x3D,  // [45] ঢ়  Dot1 Dot3 Dot4 Dot5 Dot6
  0x35,  // [46] য়  Dot1 Dot3 Dot5 Dot6
  0x26,  // [47] ৎ   Dot2 Dot3 Dot6  (2-cell: prefix Dot6 cell first)
  0x1B,  // [48] ং   Dot1 Dot2 Dot4 Dot5
  0x05,  // [49] ঃ   Dot1 Dot3
  0x04,  // [50] ঁ   Dot3
};

const char* LETTER_NAMES[50] = {
  "অ", "আ", "ই", "ঈ", "উ", "ঊ", "ঋ", "এ", "ঐ", "ও", "ঔ",
  "ক", "খ", "গ", "ঘ", "ঙ", "চ", "ছ", "জ", "ঝ", "ঞ",
  "ট", "ঠ", "ড", "ঢ", "ণ", "ত", "থ", "দ", "ধ", "ন",
  "প", "ফ", "ব", "ভ", "ম", "য", "র", "ল", "শ", "ষ",
  "স", "হ", "ড়", "ঢ়", "য়", "ৎ", "ং", "ঃ", "ঁ"
};

#define MODE_MENU  0
#define MODE_LEARN 1
#define MODE_TEST  2

int currentMode = MODE_MENU;
bool waitingForButtonInput = false;
int  testTargetIndex       = -1;
int  testCorrect           = 0;
int  testWrong             = 0;

const unsigned long debounceDelay = 50;
bool activeChord[6] = {false, false, false, false, false, false};

int lastRawState[6], confirmedState[6];
unsigned long lastChangeTime[6];
int lastRawSubmit, confirmedSubmit;
unsigned long lastSubmitChangeTime;
int lastRawEnter, confirmedEnter;
unsigned long lastEnterChangeTime;

void showMenu();
void showLearnPrompt();
void showTestPrompt();
void runLearn(int index);
void runTestQuestion(int index);
void checkTestAnswer(byte typedPattern);
void resetChord();
void vibrateBrailleDotsSequential(uint8_t pattern);
void printDotPattern(uint8_t pattern);

void setup() {
  Serial.begin(115200);
  delay(500);

  for (int i = 0; i < 6; i++) {
    pinMode(PIN_MOTOR[i], OUTPUT);
    digitalWrite(PIN_MOTOR[i], LOW);
  }
  for (int i = 0; i < 6; i++) {
    pinMode(buttonPins[i], INPUT_PULLUP);
    lastRawState[i]  = digitalRead(buttonPins[i]);
    confirmedState[i] = lastRawState[i];
    lastChangeTime[i] = millis();
  }
  pinMode(submitButtonPin, INPUT_PULLUP);
  lastRawSubmit        = digitalRead(submitButtonPin);
  confirmedSubmit      = lastRawSubmit;
  lastSubmitChangeTime = millis();

  pinMode(enterButtonPin, INPUT);
  lastRawEnter        = digitalRead(enterButtonPin);
  confirmedEnter      = lastRawEnter;
  lastEnterChangeTime = millis();

  mySoftwareSerial.begin(9600, SERIAL_8N1, PIN_DF_ESP_RX, PIN_DF_ESP_TX);
  delay(1000);

  Serial.println("\n==========================================");
  Serial.println("  BANGLA BRAILLE SYSTEM");
  Serial.println("==========================================");
  Serial.print("DFPlayer: ");
  if (!dfPlayer.begin(mySoftwareSerial, false, true)) {
    Serial.println("FAILED - check wiring!");
  } else {
    Serial.println("OK");
    dfPlayer.volume(25);
  }
  delay(500);
  showMenu();
}

void loop() {
  unsigned long now = millis();

  if (Serial.available() > 0) {
    if (currentMode == MODE_MENU) {
      char c = Serial.read();
      if (c == 'L' || c == 'l') {
        currentMode = MODE_LEARN;
        Serial.println("\n>> LEARN MODE selected.");
        showLearnPrompt();
      } else if (c == 'T' || c == 't') {
        currentMode = MODE_TEST;
        testCorrect = 0;
        testWrong   = 0;
        Serial.println("\n>> TEST MODE selected.");
        showTestPrompt();
      } else if (c == '\n' || c == '\r' || c == ' ') {
      } else {
        Serial.println("Invalid. Type L for Learn or T for Test.");
      }
    } else if (currentMode == MODE_LEARN) {
      String input = Serial.readStringUntil('\n');
      input.trim();
      if (input == "M" || input == "m") {
        currentMode = MODE_MENU;
        showMenu();
      } else {
        int val = input.toInt();
        if (val >= 1 && val <= 50) {
          runLearn(val - 1);
          showLearnPrompt();
        } else {
          Serial.println("Enter 1-50 or M for menu.");
        }
      }
    } else if (currentMode == MODE_TEST && !waitingForButtonInput) {
      String input = Serial.readStringUntil('\n');
      input.trim();
      if (input == "M" || input == "m") {
        currentMode           = MODE_MENU;
        waitingForButtonInput = false;
        testTargetIndex       = -1;
        Serial.printf("\n-- Session ended. Correct: %d | Wrong: %d --\n", testCorrect, testWrong);
        showMenu();
      } else {
        int val = input.toInt();
        if (val >= 1 && val <= 50) {
          runTestQuestion(val - 1);
        } else {
          Serial.println("Enter 1-50 or M for menu.");
        }
      }
    } else if (currentMode == MODE_TEST && waitingForButtonInput) {
      Serial.read();
      Serial.println(">> Press braille dots then hit SUBMIT button!");
    }
  }

  for (int i = 0; i < 6; i++) {
    int reading = digitalRead(buttonPins[i]);
    if (reading != lastRawState[i]) { lastChangeTime[i] = now; lastRawState[i] = reading; }
    if ((now - lastChangeTime[i]) > debounceDelay && reading != confirmedState[i]) {
      confirmedState[i] = reading;
      if (confirmedState[i] == LOW) {
        activeChord[i] = !activeChord[i];
        Serial.print("Dot "); Serial.print(i + 1);
        Serial.println(activeChord[i] ? " selected." : " removed.");
      }
    }
  }

  int submitReading = digitalRead(submitButtonPin);
  if (submitReading != lastRawSubmit) { lastSubmitChangeTime = now; lastRawSubmit = submitReading; }
  if ((now - lastSubmitChangeTime) > debounceDelay && submitReading != confirmedSubmit) {
    confirmedSubmit = submitReading;
    if (confirmedSubmit == LOW) {
      if (currentMode == MODE_TEST && waitingForButtonInput) {
        byte typedPattern = 0;
        for (int i = 0; i < 6; i++) {
          if (activeChord[i]) typedPattern |= (1 << i);
        }
        checkTestAnswer(typedPattern);
        resetChord();
      } else {
        Serial.println("(No active question - enter a number first)");
      }
    }
  }

  int enterReading = digitalRead(enterButtonPin);
  if (enterReading != lastRawEnter) { lastEnterChangeTime = now; lastRawEnter = enterReading; }
  if ((now - lastEnterChangeTime) > debounceDelay && enterReading != confirmedEnter) {
    confirmedEnter = enterReading;
    if (confirmedEnter == LOW) {
      currentMode           = MODE_MENU;
      waitingForButtonInput = false;
      testTargetIndex       = -1;
      resetChord();
      Serial.printf("\n-- Session ended. Correct: %d | Wrong: %d --\n", testCorrect, testWrong);
      showMenu();
    }
  }
}

void showMenu() {
  Serial.println("\n==========================================");
  Serial.println("  MAIN MENU");
  Serial.println("==========================================");
  Serial.println("  Type  L  -> Learn Mode");
  Serial.println("  Type  T  -> Test Mode");
  Serial.println("==========================================");
  Serial.print("Your choice: ");
}

void showLearnPrompt() {
  Serial.println("\n-- LEARN MODE --");
  Serial.println("   Type a number (1-50) to hear and feel the character.");
  Serial.println("   Type M to return to menu.");
  Serial.print("   Enter number: ");
}

void showTestPrompt() {
  Serial.println("\n-- TEST MODE --");
  Serial.println("   Type a number (1-50) to hear the character.");
  Serial.println("   Press the correct braille dots then hit SUBMIT.");
  Serial.println("   Type M to return to menu.");
  Serial.print("   Enter number: ");
}

void runLearn(int index) {
  Serial.println("\n----------------------------------------");
  Serial.printf("  LEARNING: [%d] %s\n", index + 1, LETTER_NAMES[index]);
  Serial.print("  Braille dots: ");
  printDotPattern(BRAILLE_PATTERN[index]);
  Serial.println("----------------------------------------");
  dfPlayer.play(index + 1);
  delay(1500);
  if (index == 6 || index == 46) {
    Serial.println("  (2-cell character)");
    Serial.println("  Vibrating prefix cell (Dot6)...");
    vibrateBrailleDotsSequential(0x20);
    delay(1200);
    Serial.println("  Vibrating main pattern...");
    vibrateBrailleDotsSequential(BRAILLE_PATTERN[index]);
  } else {
    vibrateBrailleDotsSequential(BRAILLE_PATTERN[index]);
  }
  Serial.println("  Done.");
}

void runTestQuestion(int index) {
  testTargetIndex       = index;
  waitingForButtonInput = true;
  resetChord();
  Serial.println("\n========================================");
  Serial.printf("  QUESTION: Braille pattern for [%d] %s ?\n", index + 1, LETTER_NAMES[index]);
  Serial.println("  Listen to speaker, then press dots + SUBMIT.");
  Serial.println("========================================");
  dfPlayer.play(index + 1);
}

void checkTestAnswer(byte typedPattern) {
  if (testTargetIndex < 0) return;
  int     index          = testTargetIndex;
  uint8_t correctPattern = BRAILLE_PATTERN[index];
  Serial.println("\n----------------------------------------");
  Serial.printf("  Character : %s\n", LETTER_NAMES[index]);
  Serial.print("  Your dots : "); printDotPattern(typedPattern);
  Serial.print("  Correct   : "); printDotPattern(correctPattern);
  if (typedPattern == correctPattern) {
    testCorrect++;
    Serial.println("  RESULT    : CORRECT!");
  } else {
    testWrong++;
    Serial.println("  RESULT    : WRONG!");
  }
  Serial.printf("  Score -> Correct: %d | Wrong: %d\n", testCorrect, testWrong);
  Serial.println("----------------------------------------");
  waitingForButtonInput = false;
  testTargetIndex       = -1;
  showTestPrompt();
}

void resetChord() {
  for (int i = 0; i < 6; i++) activeChord[i] = false;
}

void printDotPattern(uint8_t pattern) {
  bool any = false;
  for (int i = 0; i < 6; i++) {
    if (pattern & (1 << i)) { Serial.printf("Dot%d ", i + 1); any = true; }
  }
  if (!any) Serial.print("(none)");
  Serial.println();
}

void vibrateBrailleDotsSequential(uint8_t pattern) {
  Serial.print("  Vibrating: "); printDotPattern(pattern);
  for (int i = 0; i < 6; i++) {
    if (pattern & (1 << i)) {
      digitalWrite(PIN_MOTOR[i], HIGH);
      delay(400);
      digitalWrite(PIN_MOTOR[i], LOW);
      delay(800);
    }
  }
}

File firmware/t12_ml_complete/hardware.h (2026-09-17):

// Buttons, vibration motors, audio, and SD logging.
#ifndef HARDWARE_H
#define HARDWARE_H

#include <Arduino.h>
#include <SD.h>
#include <SPI.h>

#include "pins.h"

// ---------------------------------------------------------------------------
// Buttons: 6 GPIO with debounce and per-dot press/release timing.
// Timing feeds response_time and press_duration, which the model consumes, so
// it is measured from the DEBOUNCED edge -- the raw edge bounces for several
// milliseconds and would add noise the web app does not have.
// ---------------------------------------------------------------------------

typedef struct {
  bool     stable[6];
  bool     raw[6];
  uint32_t last_change_ms[6];
  uint32_t press_ms[6];       // when this dot went down, 0 if never
  uint32_t release_ms[6];
  uint8_t  mask;              // dots pressed this attempt
  uint8_t  press_order[6];
  uint8_t  press_count;
  uint32_t first_press_ms;    // 0 until the first debounced press
  uint32_t total_hold_ms;
  uint8_t  hold_samples;
} ButtonState;

static ButtonState g_btn;

static void buttons_begin() {
  for (int i = 0; i < 6; i++) pinMode(PIN_BUTTON[i], INPUT_PULLUP);
  memset(&g_btn, 0, sizeof(g_btn));
  for (int i = 0; i < 6; i++) g_btn.stable[i] = g_btn.raw[i] = false;

  // GPIO34 has no internal pull-up -- needs the external 10k resistor noted
  // in pins.h. Plain INPUT, not INPUT_PULLUP (which would fail silently here).
  pinMode(PIN_SUBMIT, INPUT);
}

static void buttons_reset_attempt() {
  g_btn.mask = 0;
  g_btn.press_count = 0;
  g_btn.first_press_ms = 0;
  g_btn.total_hold_ms = 0;
  g_btn.hold_samples = 0;
  for (int i = 0; i < 6; i++) {
    g_btn.press_ms[i] = 0;
    g_btn.release_ms[i] = 0;
  }
}

// ---------------------------------------------------------------------------
// Submit button: a 7th, separate button. response_time is measured to the
// debounced press of THIS button, not to the first dot press -- the learner
// is expected to hold the pattern on the 6 dot buttons, then press submit.
// ---------------------------------------------------------------------------

typedef struct {
  bool     raw;
  bool     stable;
  uint32_t last_change_ms;
  uint32_t press_ms;     // 0 until debounced-pressed this attempt
} SubmitState;

static SubmitState g_submit;

static void submit_reset_attempt() {
  g_submit.press_ms = 0;
}

static inline bool submit_raw() {
#if BUTTON_ACTIVE_LOW
  return digitalRead(PIN_SUBMIT) == LOW;
#else
  return digitalRead(PIN_SUBMIT) == HIGH;
#endif
}

// Call every poll iteration alongside buttons_poll(). Returns true the instant
// the submit press debounces -- i.e. once, on the rising edge.
static bool submit_poll() {
  uint32_t now = millis();
  bool r = submit_raw();
  if (r != g_submit.raw) {
    g_submit.raw = r;
    g_submit.last_change_ms = now;
  }
  if (r != g_submit.stable && (now - g_submit.last_change_ms) >= BUTTON_DEBOUNCE_MS) {
    g_submit.stable = r;
    if (r && g_submit.press_ms == 0) {
      g_submit.press_ms = now;
      return true;
    }
  }
  return false;
}

static inline bool button_raw(int i) {
#if BUTTON_ACTIVE_LOW
  return digitalRead(PIN_BUTTON[i]) == LOW;
#else
  return digitalRead(PIN_BUTTON[i]) == HIGH;
#endif
}

// Call often. Returns true if any dot changed state this call.
static bool buttons_poll() {
  bool changed = false;
  uint32_t now = millis();
  for (int i = 0; i < 6; i++) {
    bool r = button_raw(i);
    if (r != g_btn.raw[i]) {
      g_btn.raw[i] = r;
      g_btn.last_change_ms[i] = now;
    }
    if (r != g_btn.stable[i] && (now - g_btn.last_change_ms[i]) >= BUTTON_DEBOUNCE_MS) {
      g_btn.stable[i] = r;
      changed = true;
      if (r) {
        if (g_btn.first_press_ms == 0) g_btn.first_press_ms = now;
        g_btn.press_ms[i] = now;
        if (!(g_btn.mask & (1 << i))) {
          g_btn.mask |= (1 << i);
          if (g_btn.press_count < 6) g_btn.press_order[g_btn.press_count++] = i + 1;
        }
      } else {
        g_btn.release_ms[i] = now;
        if (g_btn.press_ms[i]) {
          g_btn.total_hold_ms += (now - g_btn.press_ms[i]);
          g_btn.hold_samples++;
        }
      }
    }
  }
  return changed;
}

// Mean press->release duration, ms. Dots still held are closed out at `now`,
// matching meanPressDuration() in web/braille_cell.js.
static double buttons_mean_press_duration() {
  uint32_t total = g_btn.total_hold_ms;
  uint8_t n = g_btn.hold_samples;
  uint32_t now = millis();
  for (int i = 0; i < 6; i++) {
    if (g_btn.stable[i] && g_btn.press_ms[i]) {
      total += (now - g_btn.press_ms[i]);
      n++;
    }
  }
  return n == 0 ? 0.0 : (double)total / (double)n;
}

static inline bool buttons_any_held() {
  for (int i = 0; i < 6; i++) if (g_btn.stable[i]) return true;
  return false;
}
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

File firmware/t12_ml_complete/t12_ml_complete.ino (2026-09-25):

// t12_ml_complete: Learning + ML comparison + PER-STUDENT PERSONALIZATION
//
// Identical to t11_ml_test, with one addition: every attempt is now scored
// and logged under the REAL student who is at the device, not a hardcoded
// placeholder --
//
//   1. The teacher panel now sends a `student_id` alongside each letter
//      command (see webapp/app/teacher/teacherApp.js -- sendPlay()).
//   2. This sketch reads that student_id out of the polled command and
//      reports every attempt under it (attempts.user_id), instead of the
//      literal "S01" t11_ml_test always used.
//   3. Whenever the ACTIVE student changes, this sketch fetches that
//      student's own saved per-letter state (mastery, streaks, accuracy)
//      from Supabase's `student_weaknesses` table and loads it into
//      char_state[], so prev_accuracy/prev_mastery -- the two features that
//      let the model see history the rule engine cannot -- reflect THAT
//      student's real history, not whichever student last used this board
//      since the last reboot.
//   4. After every attempt, the updated state is written back to
//      student_weaknesses (an UPSERT, same table the teacher panel's new
//      /students profile page reads), so the next session -- on this board
//      or any other -- picks up exactly where this student left off.
//
// This is deliberately ONE shared model for every student (the 1,734
// trained parameters never change here) -- personalization comes entirely
// from feeding it each student's own history as input, not from training a
// separate network per student. See docs note in the project report:
// per-student data volume (a few hundred attempts each) is far too small to
// train a separate model per student without overfitting.
//
// Serial Monitor: 115200 baud

#include <WiFi.h>
#include <WiFiClientSecure.h>
#include <HTTPClient.h>
#include <DFRobotDFPlayerMini.h>

#include "secrets.h"
#include "pins.h"
#include "hardware.h"
#include "braille_map.h"
#include "rule_engine.h"
#include "model_weights.h"
#include "inference.h"

// ---------------------------------------------------------------------------

#define TRACK_CORRECT      51
#define TRACK_WRONG        52
#define TRACK_TEST_START   61
#define TRACK_TEST_END     62
#define TRACK_THANK_YOU    63
#define TRACK_SPECIAL_CHAR 64
#define TRACK_NUMBER_BASE  70

#define DOT_ON_MS     500
#define DOT_GAP_MS    500
#define STAGE_GAP_MS  1200
#define POLL_MS       250   // safe to poll fast now that the TLS connection is reused
#define DEVICE_ID  "esp32_01"
#define DEFAULT_STUDENT_ID "S01"   // used only until the first real command arrives

static const char *SUPABASE_URL      = "https://rufaacgatrebsyxnyfbq.supabase.co";
static const char *SUPABASE_ANON_KEY = "sb_publishable_lI3qv5Xk44GAhzL4R7I2GA_4k1aUar-";

static long     g_last_id     = -1;
static uint32_t g_last_poll   = 0;
static int      g_attempt_idx = 0;
static char     g_session_id[24];
static char     g_command[16]         = "play";
static int      g_test_index          = 0;
static int      g_test_total          = 1;
static int      g_test_correct_count  = 0;
static int      g_test_wrong_count    = 0;

// The student currently named by the last-polled command, and the student
// char_state[] currently reflects. They differ for exactly one loop() pass
// after a switch -- that's the signal to reload state before scoring.
static char g_student_id[24]        = DEFAULT_STUDENT_ID;
static char g_loaded_student_id[24] = "";

// A fresh WiFiClientSecure means a full TLS handshake (0.5-3s on ESP32) per
// request -- reusing one connection avoids paying that on every poll and
// every reported attempt.
static WiFiClientSecure g_https;
static bool             g_https_ready = false;

static WiFiClientSecure &https_client() {
  if (!g_https_ready) {
    g_https.setInsecure();
    g_https_ready = true;
  }
  return g_https;
}

// ---------------------------------------------------------------------------
// Per-character state -- now understood to belong to whichever student is
// named by g_loaded_student_id, not to "the board" in general.
// ---------------------------------------------------------------------------

struct CharState {
  double accuracy;        // correct_count / total_attempts
  double mastery;         // EMA mastery (spec: alpha_correct=0.25, alpha_wrong=0.35)
  double current_streak;  // consecutive correct (post-attempt)
  double wrong_streak;    // consecutive wrong   (post-attempt)
  double prev_confidence; // last ML confidence state output
  int    total_attempts;
  int    correct_count;
};
static CharState char_state[BRAILLE_LETTER_COUNT]; // filled by load_student_state()

// ---------------------------------------------------------------------------
// Tiny JSON helpers -- pulling one named numeric field out of a flat object.
// Not a general parser: student_weaknesses rows have no nested objects or
// arrays, so indexOf+toInt/toDouble is enough and needs no library.
// ---------------------------------------------------------------------------

static long json_int(const String &obj, const char *key, long def) {
  int p = obj.indexOf(key);
  if (p < 0) return def;
  String after = obj.substring(p + strlen(key));
  if (after.startsWith("null")) return def;
  return after.toInt();
}

static double json_double(const String &obj, const char *key, double def) {
  int p = obj.indexOf(key);
  if (p < 0) return def;
  String after = obj.substring(p + strlen(key));
  if (after.startsWith("null")) return def;
  return after.toDouble();
}

// ---------------------------------------------------------------------------
// Per-student state load/save
// ---------------------------------------------------------------------------
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

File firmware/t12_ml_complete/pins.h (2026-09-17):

// Pin map and electrical notes for the ESP32-WROOM-32 build.
//
// 18 pins on a chip with ~25 usable, so it fits, but the assignment is not
// arbitrary -- read the notes before moving anything.
#ifndef PINS_H
#define PINS_H

// --- buttons ---------------------------------------------------------------
// All six have usable internal pull-ups. Deliberately NOT on 34/35/36/39:
// those are input-only AND have no internal pull-up, so they would need six
// external resistors for no benefit.
static const int PIN_BUTTON[6] = { 32, 33, 25, 26, 27, 14 };
#define BUTTON_ACTIVE_LOW 1
#define BUTTON_DEBOUNCE_MS 20

// --- submit button -----------------------------------------------------
// GPIO 12 is a strapping pin that must read LOW at boot or the chip picks
// the wrong flash voltage -- see the note below. A plain switch to GND is
// safe here specifically because it can only ever pull the pin LOW or leave
// it floating to the chip's own internal default (also LOW); a button can
// never force it HIGH, so it can't disturb the boot-time strap. This is why
// GPIO 12 is the one spare pin usable for a new button, where GPIO 0 (the
// board's existing BOOT button) is not: reusing GPIO 0 risks accidentally
// forcing the chip into flashing mode on a reset.
static const int PIN_SUBMIT = 12;

// --- vibration motors, through a ULN2803A ----------------------------------
// Use the ULN2803A, not six discrete transistors. Coin motors are inductive;
// the ULN2803A has flyback diodes built in (tie its COM pin to +5V). Driving
// an inductive motor off a bare GPIO, or off a transistor with no flyback
// path, is the single most common way this build destroys a pin.
//
// GPIO 2 and 15 are strapping pins. They are usable as outputs but are sampled
// at boot, so add 10k pulldowns on both. GPIO 12 is used for the submit
// button above, not for a motor -- see that note for why it must stay LOW.
static const int PIN_MOTOR[6] = { 21, 13, 22, 2, 15, 4 };
#define MOTOR_ACTIVE_HIGH 1

// --- DFPlayer Mini, UART2 --------------------------------------------------
// Put a 1k resistor in series with the DFPlayer's RX line: it is a 3.3V-logic
// part fed from 5V and the resistor limits current into its input protection.
#define PIN_DF_RX 16   // ESP32 receives  <- DFPlayer TX
#define PIN_DF_TX 17   // ESP32 transmits -> DFPlayer RX
#define DF_VOLUME 22   // 0..30

// --- microSD, VSPI ---------------------------------------------------------
#define PIN_SD_CLK  18
#define PIN_SD_MISO 19
#define PIN_SD_MOSI 23
#define PIN_SD_CS    5

// --- optional DS3231 RTC, I2C ----------------------------------------------
// Strongly recommended. Without a real-time clock the board cannot know how
// much time passed while it was powered off, so feature 10
// (time_since_last_practice) -- one of the 14 the model consumes -- degrades
// to a guess across sessions. See the note in learner_state.h.
#define PIN_RTC_SDA
#define PIN_RTC_SCL
#define USE_RTC 0     // set to 1 after wiring a DS3231

// --- power -----------------------------------------------------------------
// 6 motors ~480 mA peak + ESP32 ~80 mA (WiFi off) + DFPlayer/speaker ~200 mA
// => ~800 mA peak. Use a 5V 2A supply, not a laptop USB port. Put a 1000 uF
// bulk capacitor across the motor rail: without it, the motor inrush browns
// out the 3V3 regulator and the ESP32 reboots mid-session, which looks like a
// firmware crash and is not one.
//
// Never drive the motors from the ESP32's 3V3 pin. Common ground everywhere.

#endif  // PINS_H

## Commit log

2026-09-07 Make the ESP32 actually compute the model it was given
    The t6 bring-up sketch could not run at all, and once it ran it computed
    the wrong answer. Three separate faults, all uncovered by flashing it.
    1. Per-channel weights. TFLM's FULLY_CONNECTED kernel derives one
    requantization multiplier from filter->params.scale and applies it to
    every output channel; the converter emits one scale per output unit.
    Nothing rejects this -- TFLM loads the model, runs it, and silently
    uses channel 0's scale everywhere. The board returned a softmax that
    summed to 1.0 and had a different argmax. Simulating the per-tensor
    path reproduced the device's int8 output exactly, confirming it.
    trai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
    [braille_tutor.ino, t6_model.ino]
2026-09-07 Add t7: score the model against the rule engine on real presses
    p6's menu/learn/test loop with the network wired into the test path, so
    each answer is decided twice -- once by the rule engine, once by the model
    on the ESP32 -- and the two are tallied.
    Measures the four model features from actual interaction rather than
    replaying stored vectors: response_time from prompt end to the SUBMIT
    press, press_duration as the mean dot hold time (dots still held at SUBMIT
    included), retry_count from repeated prompts on the same character, and
    wrong_streak read after the attempt is scored, matching the rule engine's
    "state after the current attempt" contract.
    Type P for the report: agreement rate per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
    [t7_model_live.ino]
2026-09-08 Switch device and web audio to the gTTS voice
    The espeak-ng files were formant synthesis -- intelligible but robotic,
    which is a poor fit for a tool whose entire prompt channel is audio. The
    gTTS versions were generated on claude/repo-review-5xvi96 back in August
    and never made it onto this branch; sd_card.zip at the repo root turned
    out to be exactly those files, verified byte-identical to ec8f605 across
    all 60 tracks.
    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
2026-09-08 Speak the model's decision, and stop charging the learner for the prompt
    t7 printed CORRECT/WRONG to serial and said nothing. The prompts have been
    sitting unused on the card since Phase 0 -- tracks 51-60, sothik / vul /
    ingit / khub bhalo. Now the outcome is spoken, and then the teaching action
    is: REPEAT plays "abar chesta korun", HINT plays "ingit" AND buzzes the
    correct pattern, NORMAL_PRACTICE plays "khub bhalo" on a correct answer.
    Saying "hint" without buzzing the pattern is not a hint.
    Which decision drives the speaker is the model's when the model is live, and
    the rule engine's only as fallback. That is the entire point of the build:
    the network chooses what the learner hears, and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
    [t7_model_live.ino]
2026-09-17 Fix 7 wrong Braille dot patterns; verify all 49 chars from Wikipedia Bangladesh standard
    Audit against Wikipedia:Bengali_Braille (Bangladesh standard) found 7 consonants
    with incorrect dot patterns — mostly India/Bharati Braille bleeds from the original
    mapping. Fixed patterns (all now confirmed correct for Bangladesh):
    খ (id=12): [4,6] → [1,3,4,6]
    ঝ (id=19): [3,5,6] → [1,3,5,6]
    ফ (id=32): [1,2,4] → [2,3,5]
    ভ (id=34): [4,5] → [1,2,3,6]
    য় (id=45): [2,3,5,6] → [2,6]
    ঃ (id=48): [2,3] → [6]
    ঁ (id=49): [4] → [3] (was wrongly using the virama ্ pattern)
    All 40 previously correct characters (10 vowels + 30 consonants/modifie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
2026-09-17 Implement two-cell Braille for ঋ and ৎ; firmware vibrates prefix then collects answer
    Bangladesh Braille standard requires two cells for ঋ and ৎ:
    ঋ (id=6): prefix [5] → answer [1,2,3,5]
    ৎ (id=46): prefix [5] → answer [2,3,4,5]
    Changes:
    - data/braille_map.json: add "cells" field to ঋ and ৎ, fix ৎ dots from
    placeholder [2,3,6] to correct second cell [2,3,4,5], mark ৎ verified=true,
    update _notes and _warning; verified_count now 50/50.
    - tools/gen_braille_header.py: emit BRAILLE_PREFIX[] array alongside
    BRAILLE_PATTERN[] — 0 for single-cell letters, prefix bitmask for two-cell.
    - firmware/braille_tutor/braille_map.h: regenerated — BRAILLE_PREFIX added,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
    [braille_tutor.ino]
2026-09-17 Add Teacher Panel with real-time ESP32 sync and update hardware tests
    - Web/Mobile Teacher Dashboard (web/teacher.html, web/index.html):
    - Implement real-time closed-loop teacher panel with sequential & random learning modes
    - Integrate instant decision engine with missing/extra Braille dot hints and Bangla audio feedback
    - Auto-advance to next word/character immediately upon correct student submission
    - Provide student analytics with real-time latency (<200ms) and mastery curves
    - Include built-in ESP32 hardware keypad simulator for live testing
    - Firmware & Bring-Up Tests (firmware/tests/, firmware/braille_tutor/):
    - Update t1_blink_serial with 6-dot button matrix chord readin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
    [braille_tutor_case.scad, top_panel.stl, top_panel_layout.scad]
2026-09-17 Add teacher panel with learning and test modes, Supabase migration
    - web/teacher.html: Apple-inspired dark Bangla teacher dashboard
    Sequential mode: auto-advance on correct, ML hint on wrong
    Random mode: 50-letter grid, teacher picks any letter
    Hardware simulator pad (6 dots + submit) for testing without ESP32
    Shared real-time result panel (dot comparison, teaching action, hint)
    - web/teacher.js: ES module with full logic
    50 verified Braille letters embedded (Bangladesh standard)
    Supabase polling at 500ms (attempts table, created_at filter)
    remote_commands POST for ESP32 (command: play or test)
    Test mode: multi-select letters, shuffle, run, results card
    Weakness upsert to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
2026-09-17 Redesign teacher panel: green mobile UI matching mockup screenshots
    - Complete rewrite of teacher.html with white/green mobile-first design
    - Green accent (#16a34a), white cards, light gray background
    - Sticky header with ESP32 status badge, student/mode info
    - Tab pills for ক্রমানুসারে / এলোমেলো learning modes
    - Category filter tabs (সব / স্বরবর্ণ / ব্যঞ্জনবর্ণ) for letter grids
    - Letter grid with mastery dots (green/amber/red/gray per student_weaknesses)
    - Selected letter info card (green background) in random and test select screens
    - Sequential mode: char display, braille dots, result panel, progress bar, sim
    -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
2026-09-17 Verify all 50 Braille patterns against Wikipedia Bangladesh Braille standard
    Cross-referenced all 50 Bengali letters against bn.wikipedia.org/wiki/বাংলা_ব্রেইল.
    All 10 disputed letters confirmed matching BNBC exactly:
    - ঋ: prefix=dot5, main=dots1235 (two-cell) ✓
    - খ: dots 1,3,4,6 ✓
    - ঝ: dots 1,3,5,6 ✓
    - ফ: dots 2,3,5 ✓
    - ভ: dots 1,2,3,6 ✓
    - ঁ: dot 3 ✓
    - ঃ: dot 6 ✓
    - ং: dots 5,6 ✓
    - ৎ: prefix=dot5, main=dots2345 (two-cell) ✓
    - য়: dots 2,6 ✓
    Updated braille_verified PNGs, braille_map.json, braille_map.h, braille_map_fallback.js
    to regenerated verified images. No dot pattern corrections were needed.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
2026-09-17 Propagate verified BNBC Braille patterns to all project assets
    Updated all files from the authoritative data/braille_map.json (50 letters,
    all verified against Wikipedia Bangladesh Braille standard):
    - web/data/braille_map.json: replaced stale PLACEHOLDER_BHARATI data with
    verified BNBC patterns; 8 entries had wrong dots (খ, ঝ, ফ, ভ, য়, ৎ, ঃ, ঁ)
    - assets/braille/index.json: regenerated via gen_braille_images.py (same 8 fixed)
    - assets/braille/*.svg + *.png: regenerated all 50 SVG and PNG images so
    visual assets match the corrected dot data
    - assets/braille/_contact_sheet.png: updated contact sheet
    - firmware/braille_tutor/braille_map.h: regenerated (now shows verified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
2026-09-17 Fix two silent bugs found in config audit
    1. teacher.js simulator source field: 'simulator' → 'web'
    The attempts table CHECK constraint only allows source IN ('web','esp32',
    'synthetic'). Every simSubmit() POST was silently failing with a constraint
    violation; no simulator rows were ever saved to Supabase.
    2. braille_map_fallback.js: add named ES module export
    app.js imports { FALLBACK_MAP } but the file only assigned to
    window.BRAILLE_MAP_FALLBACK with no export. FALLBACK_MAP was always
    undefined, causing a TypeError crash if the primary JSON fetch failed.
    Added: export const FALLBACK_MAP = window.BRAILLE_MAP_FALLBACK;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
2026-09-17 Expand model to 8 features, retrain on 923 real rows, fix sync retry
    - rule_engine_gen.py: FEATURE_COUNT 4->8, add prev_accuracy, prev_mastery,
    hint_count, current_streak to model input vector (matches presentation)
    - models/metrics_final.json: 8 features on 923 real + 1303 synthetic,
    teaching real-only 96.1%, confidence real-only 89.8%, all 6 classes F1>0.89
    - models/metrics_balanced.json: 3779-row balanced run results
    - models/metrics_2k.json: 2207-row 4-feature intermediate run
    - web/storage.js: add 30s auto-retry timer on sync failure + retryNow()
    - web/app.js: wire syncStatus click to retryNow() with pointer cursor
2026-09-17 Fix sync 400: sanitize streak constraint violation in flush()
    The DB enforces: current_streak = 0 OR wrong_streak = 0.
    New attempts satisfy this by construction (applyOutcome always zeroes
    one side), but 9 rows stuck in the offline queue were logged by an
    earlier code version before that invariant was enforced.
    Before each batch send, use is_correct as the truth source to clamp
    the violating field to 0, clearing the stuck queue.
2026-09-17 Export 1000 real rows from Supabase as real_v3.csv
    P01=315, P02=320, P03=364, P04=1
    teaching: REPEAT=230, HINT=144, NORMAL=626
    confidence: CONFIDENT=184, HESITANT=513, GUESSING=303
    9 rows still queued on P03 device (pending hard refresh + sync)
    [real_v3.csv]
2026-09-17 Retrain on 1000 real rows (real_v3): TA=98.56%, CS=91.37% real-only
    Dataset: 1000 real + 1242 synthetic = 2242 total (44.6% real), 8 features
    Teaching action - combined: 99.41% real-only: 98.56% majority: 46.59%
    Confidence state - combined: 94.07% real-only: 91.37% majority: 42.43%
    Per-class TA: REPEAT F1=0.994, HINT F1=0.989, NORMAL F1=0.997
    Per-class CS: CONFIDENT F1=0.938, HESITANT F1=0.928, GUESSING F1=0.960
    [synthetic_2k.csv]
2026-09-17 Expand model to 8 features: update spec, regenerate engines, export C weights
    spec/engine_spec.json:
    prev_accuracy, prev_mastery, hint_count, current_streak -> model_input: true
    Validated empirically: confidence real-only 64.7% -> 91.4% vs 4-feature baseline
    tools/gen_engine.py regenerated (all 3 identical):
    web/rule_engine.js, firmware/rule_engine.h, tools/rule_engine_gen.py
    Parity test: Python == JS, 500 vectors, 100% match
    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
2026-09-17 Remap motor pins to match physical wiring, add learning module and sync tests
    Adds t10_learning (audio + sequential vibration teaching, two-stage input
    for ঋ and ৎ), t_sync_test and t_motor_test bring-up sketches, and remaps
    PIN_MOTOR to { 21, 13, 22, 2, 15, 4 } across all firmware to match the
    verified physical button-to-motor sync.
    [hardware.h, pins.h, t10_learning.ino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]
2026-09-17 Add t11_ml_test: learning sketch with ML vs rule engine comparison
    firmware/t11_ml_test/ is a self-contained Arduino sketch folder.
    Upload t11_ml_test.ino to the ESP32 to see, after every attempt:
    Rule Engine: TA=REPEAT CS=HESITANT
    ML Model: TA=HINT CS=GUESSING
    TA:MISMATCH CS:MISMATCH streak c=0 w=2 acc=0.33 mastery=0.18
    Changes vs t10_learning.ino:
    - Includes rule_engine.h / model_weights.h / inference.h
    - CharState struct tracks per-character accuracy, mastery, streaks
    within the session (resets on reboot)
    - wait_for_submit() now measures response_time_ms
    - learning_round() calls log_ml_comparison() after every wrong/correct
    attempt so both outputs are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
    [hardware.h, pins.h, t11_ml_test.ino]
2026-09-17 Add t11_testing module, fix teacher panel, sync verified braille map
    - firmware/tests/t11_testing: new assessment-only sketch -- audio-only
    prompt (no vibration cue), single input+submit per letter, batch
    progress via remote_commands.test_index/test_total, Serial summary
    after the last item. Reuses one WiFiClientSecure connection instead of
    a fresh TLS handshake per request (was the main source of lag).
    - t10_learning: same persistent-connection fix, faster poll interval,
    synced braille_map.h to the Wikipedia-verified 50-letter map (previous
    copy still had 38 placeholder patterns, including a wrong ৎ pattern).
    - web/teacher.js: call the previously-unreferenced init() (nothing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
    [hardware.h, pins.h, t10_learning.ino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]
2026-09-17 Report learning/ML attempts to Supabase, remove web input paths, update docs
    - t10_learning: was never reporting to Supabase at all -- add
    report_attempt() (persistent-connection POST to attempts, every retry
    logged, not just the final correct one).
    - t11_ml_test: was Serial-only despite computing real ML/rule-engine
    features -- now reports to attempts using the model's actual decision
    and the sketch's real per-letter accuracy/mastery/streak tracking,
    not placeholders. Also fixes missing buttons_any_held() (compile
    error), wrong PIN_MOTOR mapping, and applies the same persistent-TLS-
    connection + faster-poll fixes already made to t10/t11_testing.
    - web/teacher.js + teacher.html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
    [hardware.h, pins.h, t10_learning.ino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]
2026-09-17 Update README and firmware/tests/README: reflect current sklearn pipeline
    - README.md: model.tflite -> model_weights.h, 4 features -> 8 features,
    790 params -> 1734 params, TFLite -> sklearn float32 C arrays,
    real-only accuracy 98.6% TA / 91.4% CS, dataset 1000+1242 rows,
    hardware fit 7.1 KB (no arena), t11_ml_test Serial Monitor only,
    layout table updated with dataset/ models/ tools entries
    - firmware/tests/README.md: t6_model marked legacy, train_and_export.py
    replaces train.py+tflite_to_header.py, TFLite per-channel section
    replaced with sklearn->C array deployment section
2026-09-17 Add user profile system and smooth UI for phone use
    - Profile screen shown on first visit: user enters name + ID before starting
    - Profile saved to localStorage (braille.profile key), persists across sessions
    - Header user badge shows avatar initials, name, ID with a পরিবর্তন button to re-open profile
    - boot() gates on profile: shows profile screen if none exists, runs app normally if profile set
    - loadLearner() now reads userId from saved profile instead of a removed HTML input
    - wireProfileEvents() handles save (Enter key + click), change-profile button, input validation
    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
2026-09-18 Build final-demo presentation deck from official EEE 416 template
    Fills the 32-slide BUET course template with the project's current
    verified state (1,734-param dual-head model, 98.56%/91.37% real-only
    accuracy, 50/50 Braille verified, 1000 real rows) instead of stale
    figures from earlier progress reports. Two slides with no applicable
    content (circuit simulation, PCB/3D rendering) were cut.
    - Regenerated all 12 architecture diagrams plus 4 new ones (literature
    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
2026-09-18 feat: Bangla Braille learning and testing device project presentation release
    - BUET EEE 416 (Microprocessor and Embedded Systems Sessional) Group 08 Section A2
    - Team members: Santu Nag (2106055), Md. Adib Hasan Audhi (2106056), Mishat Hasan Milon (2106059), Khalid Mehebub (2106065)
    - Reorganize project presentation materials into docs/presentation/
    - Clean up root directory and remove redundant binary files and archives
    - Comprehensive documentation with system architecture, hardware specifications, and reproduction guide
    - Add full empirical participant dataset and calibrated synthetic training sets
    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
    [real.csv, real_v2.csv, synthetic.csv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]
2026-09-25 feat: add t12 personalized firmware, 3D enclosure models, webapp routes, and project report
    [braille_tutor_case.scad, case_base.scad, case_base.stl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]
2026-09-25 feat: auto-detect recent ESP32 activity on page load to light up connected badge
2026-09-25 fix(learn): auto-advance sequential learning, add Braille dots to random mode, and fix ESP32 connection detection
2026-09-25 fix(connection): restrict ESP32 active window to 45s and timeout to searching after 60s
2026-09-25 feat(heartbeat): implement 4s ESP32 heartbeat ping and real-time connection status in webapp
2026-09-25 feat(learn): add explicit 'শেখান' and 'থামান' buttons in random mode
2026-09-25 feat(testing): disable vibration motors in test mode, cap at 10 letters, and add Bengali voice announcements with number scores
    [t11_testing.ino, t12_ml_complete.ino]
2026-09-25 feat(audio): add 'বিশেষ বর্ণ' prompt (Track 64) for two-stage characters ঋ and ৎ
2026-09-25 fix(firmware): sanitize student_id parsed from remote_commands
    student_id is later concatenated raw into JSON bodies in
    report_attempt()/save_student_weakness() with no escaping. A value
    containing a '"' or '\' (e.g. from a mistyped/pasted student code)
    would corrupt that JSON and silently drop the attempt. Strip both
    characters at parse time in poll_supabase(), matching the same
    sanitization already applied client-side in the teacher panel's
    setStudentId().
    [t12_ml_complete.ino]
2026-09-26 fix(learn): stop immediately on 'পাঠদান থামান' click and ignore any new entries
